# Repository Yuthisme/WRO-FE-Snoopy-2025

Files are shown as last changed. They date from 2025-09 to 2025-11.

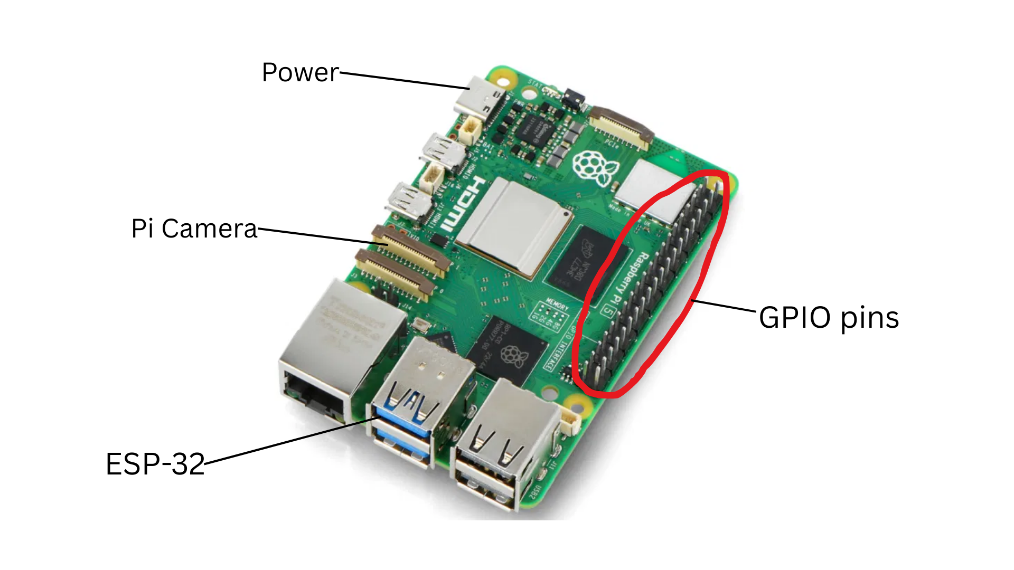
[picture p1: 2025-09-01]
schemes/pi.png

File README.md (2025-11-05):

# <ins> Snoopy: WRO Future Engineer 2025 </ins>
---
## Table of Content
1. [Introduce the team](#1introduce-the-team)
2. [What is WRO?](#2what-is-wro)
   - [Why do we choose Future Engineer](#why-we-chose-future-engineer)
3. [Robot](#3robot)
4. [Video](#4-video)
5. [Hardware](#5-hardware)
   - [Mobility Management](#mobility-management)
     - [3D design](#3d-design)
     - [Motor](#motor)
     - [Differential](#differential)
     - [Steering](#steering)
     - [Chassis](#chassis)
     - [Assembly](#assembly)
   - [Power and Sense management](#power-and-sense-managament)
     - [Component](#component)
     - [Sensor](#sensor)
     - [Power Supply](#power-supply)
     - [Microcontroller](#microcontroller)
     - [Wiring and Scheme](#wiring-and-scheme)
6. [Software](#6software)
   - [ROS2](#ros2)
   - [OpenCV](#open-cv)
   - [Code for components](#code-for-component)
7. [Obtacle Management](#7obstacle-management)
   - [Strategy](#strategy)
     - [Opene Challenge](#open-challenge)
     - [Obstacle Challenge](#obstacle-challenge)
8. [Conclusion](#8-conclusion)
---
# 1.Introduce the team
---
<p>

</p>
<p><ins><i>Snoopy at WRO INTERNATIONAL 2024</i></ins></p>

Snoopy is a team of passionate young engineers. We started back in grade 11(2024), when three high school students and our robotics teacher teamed up after being inspired by our seniors winning the Startup Idea Award at the WRO International Round in Panama. Last year, we joined the World Robotics International Round in Türkiye, where we learned a lot and made plenty of new friends. [Instagram](https://www.instagram.com/snoopy.cambodia?utm_source=ig_web_button_share_sheet&igsh=ZDNlZDc0MzIxNw==)

---
### Snoopy's Team:
<p>
1. Reaksa Chhoeun<br>
<br>
- Team's Advisor<br>
- "Don't give up"<br>
</p>

<p>
2. Seyha Hoy<br>
<br>
- Team's Coach<br>
- "Stay Curious"<br>
</p>

<p>
3. Leangheng Vongchhayyuth<br>
<br>
-Team's Leader<br>
-Team's coder<br>
-16 years old<br>
-<b>School:</b> AUPP High School-Foxcroft Academy<br>
-"God did"<br>
</p>

<p>
4. Bunchhoeun Rattanakboth<br>
<br>
-Team's mechanics<br>
-16 years old<br>
-<b>School:</b> AUPP High School-Foxcroft Academy<br>
-"What Should I say?"<br>
</p>

<p>
5. Sreng Kimroathpiseth<br>
<br>
-Team's wiring<br>
-17 years old<br>
-<b>School:</b> AUPP High School-Foxcroft Academy<br>
-"Bro idk too"<br>
</p>

<br>
<p><ins><i>Team Picture with coach</i></ins></p><br>
<br>
<p><ins><i>Team Picture</i></ins></p><br>
   
---
# 2.What is WRO?
---
WRO (World Robotics Olympiad) is a global robotics competition for young people. It aims to foster creativity, design, and problem-solving skills through challenging and educational robotics activities. WRO involves teams designing and programming robots to complete tasks or solve problems in various categories. [link](https://wro-association.org/)

## Why we chose Future Engineer?

Future Engineer is one of the interesting categories out of all four, because we love to do challenging and complicated things. We chose this category because we all have an interest in cars and want to be involved in that type of engineering, which is our goal to become engineers in the future.

---
# 3.Robot
---

<br>
<p><i>Front</i></p><br>
<br>
<p><i>Back</i></p><br>
<br>
<p><i>Right</i></p><br>
<br>
<p><i>Left</i></p><br>
<br>
<p><i>Top</i></p><br>
<br>
<p><i>Bottom</i></p><br>

---
# 4. Video
---
- [Youtube](https://youtube.com/@snoopywrocambodia?si=DruGofx_E3J2LwbV)
  - [Open Challenge](https://youtu.be/84BnV2V4fig?si=563qHp9vC6NSgZDj)
  - Obstacle Challenge

---
# 5. Hardware
---
Our robot is built to meet all the game’s requirements. It runs on two motors: one for steering and one for driving. For sensors, we use LiDAR to detect walls, a camera to recognize traffic light colors in the obstacle challenge, and an IMU to track the car’s position.

## Mobility management
### 3D design
   <P>Some parts of our robot were 3D design on our own, and some parts we found online and modified them.</P><br>

| Owned 3D design | Online 3D design  |
|--- |--- |
| [Robot's Layer](https://github.com/Yuthisme/WRO-FE-Snoopy-2025/blob/main/models/the%20robot.f3z)| [Differential Grear](https://github.com/Yuthisme/WRO-FE-Snoopy-2025/blob/main/models/differenetial%20gear.f3d)|
| [Camera mount](https://github.com/Yuthisme/WRO-FE-Snoopy-2025/blob/main/models/cam%20mount.f3d)| [Differential Case](https://github.com/Yuthisme/WRO-FE-Snoopy-2025/blob/main/models/differential%20case.f3d) |
| [Battery Checker Holder](https://github.com/Yuthisme/WRO-FE-Snoopy-2025/blob/main/models/bat%20checker%20v5.f3d)| |
| [Battery Holder](https://github.com/Yuthisme/WRO-FE-Snoopy-2025/blob/main/models/battery%20holder_.f3d)| |
|[Right rear wheel holder](https://github.com/Yuthisme/WRO-FE-Snoopy-2025/blob/main/models/right%20rear%20wheel%20holder.f3d)| |

#### Robot's Layer
<br>
The robot’s chassis is built in three layers: bottom, middle, and top.<br>
  - <b> Chassis: </b> This layer houses the motors with encoders, the steering servo, and the differential. A cutout at the rear of the chassis accommodates the differential, ensuring smooth operation. At the front, the servo and servo rod control the steering of the front wheels.
  - <b> Middle Layer: </b> This layer supports most of the sensors and electronic components, including the camera, LiDAR, motor driver, camera mount, ESP32, battery, and battery checker.
  - <b> Top Layer: </b> The top layer is reserved for the main computing and power components, such as the Raspberry Pi 5, our custom-designed PCB, and the buck converter.

#### Camera Mount:
  <br>
 The camera mount is positioned high to allow the camera to easily detect traffic lights during the obstacle challenge. Its base is precisely aligned with the LiDAR mounting screw holes, as the LiDAR is mounted directly beneath the camera. 
 
#### Battery Checker Holder:
bat checker<br>
This holder is designed to securely house the battery checker at the back of the robot. The holder’s hole is 10 mm larger than the battery checker to ensure a snug fit.

#### Battery Holder
bat holder<br>
The battery holder is designed to secure the battery in place. Similarly, its hole is 10 mm larger than the battery to prevent it from falling out while the robot is in motion.

#### Right Rear Wheel Holder
<br>
This component stabilizes the drive shaft extending from the differential to the right rear wheel.

#### Differential Gear
  <br>
   We sourced the design from GrabCAD and modified the central hole of the gear to fit the motor shaft precisely.[link](https://grabcad.com/library/lego-technic-gears-1)
   
#### Differential Case
  <br>

  We adapted the design from [Team StormsNGR](https://github.com/MoCsabi/WRO2024-FE-StormsNGR/blob/main/models/Differential%20Gear%20House.stl), modifying certain parts to accommodate a different motor and to provide a secure mount for the motor.

### Motor
<br>
We selected the JGB37-520B DC motor with encoder to track the distance traveled by the robot. This allows us to determine the motor’s speed, control when the robot needs to turn, and monitor wheel rotations. As a result, the robot can stop precisely at its starting point and execute accurate left and right turns.

### Differential
<br>

The robot uses a LEGO differential, which allows the left and right wheels to rotate at different speeds when turning, enabling smooth cornering. We also chose this differential because it easily connects to the LEGO wheels used on the robot, simplifying assembly and ensuring reliable performance.

### Steering
Front Wheel<br>
The robot uses a servo motor and a servo rod for steering. The servo is controlled to rotate at specific angles using a PID controller. The servo rod is attached to an arm connected to the servo shaft, which pushes or pulls the linkage as the servo rotates, causing the wheels to pivot in the desired direction.

### Chassis
<br>

- <b>Front section</b>: Designed to allow smoother turning and wheel rotation without interference from other parts of the robot. This section also accommodates the servo motor.
- <b>Middle section</b>: Serves as the mounting area for the motor. The motor driver and LiDAR are mounted upside down on the second layer of the car, connected above this section.
- <b>Rear section</b>: Houses the differential and rear wheels, with a cutout that allows the differential to rotate freely. This section also connects the rear wheels to the differential.

### Assembly
#### Design and Planning
<b>Step 1:</b>  We searched up some designs of the chassis online or took a look at last season's teams for inspiration.<br>
<b>Step 2:</b> We discuss and finalize the design <br>
<b>Step 3:<b> We start to design the chassis, the 1st and 2nd layer,  then the other components mount of the robot.<br>
<b>Step 4:</b> We decide what material to use for the chassis, the robot’s layer, and the components mount.<br>

#### Fabrication
- For the Chassis, we chose aluminum since it’s light and strong.
- For the robot’s layer, we use acrylic; it’s light, strong, and easy to laser cut.
- For the other component’s mount, we 3D printed it.

#### Assembly

Step 1: Cut out the car chassis using Aluminum<br>
Step 2: 3D print the Camera Mount, Differential Case, Battery  Holder, Battery Checker Holder, Right Rear Wheel Holder and the Differential Gear.<br>
Step 3: Cut the Middle layers and the Top layers with Acrylic.<br>
Step 4: Installation of the Chassis<br>

<br>

1. Connect the servo’s mount, then connect it to the Servo
2. Connect the Servo arm to the servo 
3. Connect the servo rod with the servo arm
4. Connect the steering with the wheel
5. Install the differential, the wheel, and the motor

Step 5: Installation of the middle layer<br>



1. Connect the camera mount with the lidar 
2. ESP-32 behind the camera mount
3. The motor driver behind the lidar
4. Install the battery holder
5. Install the battery checker holder

Step 8: Installation of the top layer<br>

<br>

1. The PCB at the front
2. The Raspberry Pi 5 in the middle
3. The buck converter must be at least 50mm longer.

<i>Note: We install the chassis, then continue installing the 2nd and 3rd layer by putting them on top of each other.</i>

## Power and Sense Managament
### Component
At the core of our robot, we have a Raspberry Pi 5 with 8GB of RAM. This Raspberry Pi 5 processes all the data sent to the robot by the other components, such as the lidar, camera, motor, and IMU. Here are the listing and purpose:

<p><b>IMU (Inertial Measurement Unit)</b></p><br>
<p>A device that measures the orientation and acceleration of a moving object. In our self-driving robot, the IMU provides crucial information about the robot's orientation, angular velocity, and linear acceleration. This data is essential for vehicle state estimation, sensor fusion, and control systems.</p><br>

<p><b> LiDAR (Light Detection and Ranging)</b></p><br>
<p>It emits laser beams to measure distances to objects in its surroundings. It provides a 3D point cloud representation of the environment, enabling the robot to perceive obstacles, terrain, and other relevant features. Key applications of LiDAR in your self-driving robot include obstacle detection and avoidance, mapping and localization, and terrain analysis.</p><br>

<p><b> Raspberry Pi 5 16GB RAM</b></p><br>
<p>The Raspberry Pi 5 serves as the brain of our self-driving robot. It processes sensor data, executes control algorithms, and communicates with other components. Key functionalities of the Raspberry Pi 5 in your robot include sensor data processing, algorithm execution, communication, and machine learning.</p><br>

<p><b> Motor Driver</b></p><br>
<p>A motor driver is an electronic circuit that controls the speed and direction of electric motors. It acts as an interface between the Raspberry Pi 5 and the motors, allowing the robot to move forward and backward. Key features of a motor driver include power amplification, direction control, and speed control.</p><br>

<p><b>Motor</b></p><br>
<p>Motors are the actuators that convert electrical energy into mechanical energy, enabling the robot to move. In our self-driving robot, motors are typically used to drive the wheels. Key characteristics of motors for self-driving robots include torque, speed, and efficiency.</p><br>

<p><b> Servo Motor </b></p><br>
<p>A servo motor is a rotary actuator with a built-in position sensor. It allows precise control of the angle of rotation, making it ideal for steering mechanisms in self-driving robots. Key features of a servo motor include precision and holding torque.</p><br>

<p><b>Raspberry Pi Camera Module 3</b></p>
<p>The Raspberry Pi Camera Module 3 is a 12MP Sony IMX708 autofocus camera; stills up to 4608×2592, video up to 1080p60, with HDR and improved low-light; CSI ribbon connection; works with Picamera2/OpenCV.</p><br>
 
<p><b>ESP32</b></p><br>
<p>The ESP32 is a powerful microcontroller with built-in Wi-Fi and Bluetooth. It has many pins for sensors and devices, making it popular for IoT, robotics, and smart gadgets. It’s low-cost, fast, and easy to program with Arduino or MicroPython. We use this to receive data from the Lidar and send the data to the Raspberry Pi</p><br>

<p><b>RGB</b></p><br>
<p>RGB stands for Red, Green, and Blue, the three primary colors of light. By mixing these colors in different intensities, almost any other color can be created. We use this to tell the status of the robots.</p>

### Sensor
Our robots use multiple sensors for different purposes, like the Lidar we use to detect the wall since it uses lasers to measure the distance between the wall and the robot, so it’ll make it easy to identify how far or how close the robot is when we test the robots in both open and obstacle challenges. The other sensor that we use is the Camera, which we use to detect the color of the traffic light during the obstacle challenge, so it can send a signal to the robot that either turn left or right. We also use IMU to track the position of the robot, we use it to count how many laps the robot has traveled, and to make the robot move in a fixed position.

### Power Supply
We chose an 11.1V LiPo battery since it can provide us with enough power to run all of our components, such as the Raspberry Pi, servo, motor, and sensors. Since the servo, IMU, and motor encoder have a maximum voltage of 5V, we use a buck converter to step down the 11.1V from the battery to 5V, which is then supplied to the components that require only 5V. Additionally, we use a boost converter to step up the 11.1V to 12V to power the motor.

### Microcontroller
The robot Raspberry Pi serves as the main controller, managing all operations. We selected the Raspberry Pi for its processing speed, ease of integration with other components, and the ability to upload or modify code via SSH, eliminating the need to connect a USB cable like with Arduino or ESP32.

### Wiring and Scheme
<p>For wiring, we chose to design our own PCB board that has all the pins that indicate each GPIO pin of the Raspberry Pi 5 and a JST pin for power supply, RGB, Motor encoder, Motor Driver, Motor, IMU, and push button. The screw terminal connectors for the power supply.</p><br>
pi<br>
<br>
<br>
<p>This schematic illustrates a robot control system designed around a Raspberry Pi 5, featuring an IMU for orientation, encoders for wheel feedback, DC motors for driving, and a servo for steering or actuation.</p>

---
# 6.Software
---
	
 We decided to use ROS2 as the main framework for our robots, while OpenCV for the camera. ROS2 provides the communication framework that connects different parts of the system, while OpenCV enables the car to process camera images and recognize objects. Together with sensors like LiDAR and cameras, they allow the robot to detect obstacles, identify lanes, and make driving decisions. For the full software documentation including solutions and how we approach problem please go to [CODE DOCUMENTATION](src/README.md).

## ROS2

<br>

ROS2, the Robot Operating System 2, acts as the central nervous system of the self-driving car. It provides a flexible framework for organizing and coordinating various software components, including nodes, topics, and services. Nodes perform specific tasks, such as sensor data processing, control algorithms, or communication with other nodes. Topics are channels for publishing and subscribing to messages, enabling data exchange between nodes. Services provide a request-response mechanism for nodes to interact and request services from each other.

## Open CV

OpenCV, the Open Source Computer Vision Library, empowers the car to "see" the world around it. It enables a wide range of computer vision techniques, including image processing, feature detection, object detection and tracking, and optical flow.

To integrate these components, a ROS2-based system is meticulously crafted. LiDAR data is captured and processed to generate a point cloud representation of the environment, while camera images are captured and pre-processed using OpenCV to enhance clarity and contrast. LiDAR-based perception uses point cloud data to detect obstacles and create a 3D map of the surroundings, while camera-based perception employs OpenCV to identify lanes, traffic signs, and other relevant visual cues.

## Code for Component
- [IMU](src/bno055_imu)
- [Messages](src/fe_interfaces)
- [Hole Checker](src/find_hole)
- [Lidar Package for ROS2](src/ldlidar_stl_ros2)
- [Lidar Codes](src/lidar_ros2)
- [Motor Control](src/motor_control)
- [Robot automation](src/my_robot)
- [Object Detection](src/object_detection)
---
# 7.Obstacle Management

There are two challenges: the Open Challenge and the Obstacle Challenge. The open challenge requires the robot to drive three full laps around the game field and stop at its starting point. While the Obstacle challenge requires the robot to drive 3 full laps too but there are traffic lights and a parking lot. GREEN = right, RED = left. [Officials Game Rule](https://wro-association.org/wp-content/uploads/WRO-2025-Future-Engineers-Self-Driving-Cars-General-Rules.pdf)

## Strategy 
### Open Challenge
<br>
Our robot begins its run when the push button is pressed, activating its wall-tracking system. Using LiDAR and IMU data, the robot simultaneously monitors both the left and right walls to stay centered. When the left or right wall shows a gap (detected as a hole), the robot recognizes it as a turn. It then follows the wall, making a precise 90° turn, which is counted as one completed turn. If no hole is detected, the robot continues moving forward while keeping track of both walls. The ESP32 ensures fast and reliable data transfer from the LiDAR to the Raspberry Pi 5, which fuses data from the IMU and Pi Camera Module v2 for orientation, stability, and lane recognition. After completing 12 turns, the robot executes a controlled stop. This strategy minimizes wall contact, ensures stable turns, and achieves accurate lap completion.

### Obstacle Challenge
In the Obstacle Challenge, our approach is extended to include traffic sign recognition and parking. The camera identifies red and green pillars, which dictate whether the vehicle should stay on the right or left side of the lane. The LiDAR, with data again transmitted through the ESP32 module, confirms obstacle distances and ensures safe path planning, while the IMU stabilizes navigation during detours. The Raspberry Pi 5 executes a state-machine control system that interprets sign information, chooses the correct lane, and adjusts the steering smoothly to avoid moving signs, since avoiding contact yields higher points. After completing three laps, the camera and LiDAR are used together to detect the magenta parking lot boundaries. The vehicle then executes a precise parallel parking maneuver, carefully controlling the steering servo and motors to ensure it is fully inside the parking space without touching the barriers. The RGB LEDs signal the vehicle’s status throughout (ready, running, or parking), helping the team and judges monitor progress.

---
# 8. Conclusion
Through countless hours of design, coding, testing, and teamwork, Team Snoopy Cambodia has developed a robot that balances innovation with reliability. By combining ROS2, OpenCV, LiDAR, IMU, and a Raspberry Pi 5, we created a self-driving system capable of navigating open tracks, handling obstacles, and performing precise self-parking.<br>
This journey has been more than just building a robot it has been about learning, problem-solving, and pushing our creativity to new levels. Each challenge taught us how to improve our engineering, strengthen our teamwork, and bring our vision closer to reality.<br>
As we move forward to WRO 2025, we are proud of what we’ve achieved and excited to keep innovating, improving, and representing Cambodia on the international stage.

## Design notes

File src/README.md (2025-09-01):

Control software
====

### OPEN CHALLENGE 

For open challenge, our approach to the problems are very simple. This could be changed later if we qualified to international rounds, however for the current national rounds the solutions will be very simple as the inside wall of the gamefield is static. 

Firstly, before the robot needs to do anything it needs to check whether its going clockwise or counter-clockwise. The solution for this problem is to check for the hole before it **reaches** the hole. To do this we had to do some basic trigonometry:

 

We check for holes using a static range in our LiDAR scanner, for example we want to check from 30-60cm in front of us. We would first use the Pythagorean theorem: $a^2 + b^2 = c^2$. We then do this for another hypotenuse as there are 2 range, 30cm and 60cm. Using the two hypotenuse we can find the angle by using: $Tan(θ) = opposite/adjacent$. After finding out this angle we can use it into our code to scan for those specifics angles, and there will be specific ranges we can use to compare to the angle to check whether those laser beams past through our ranges or not. If all of the laser beams divided by 2 passes through our range, then it would be considered a wall. 

Moving on here is a flowchart of how the first part of our open challenge round will be like.

```mermaid
flowchart TD
    A(["Button pressed"]) --> B{"Check Both Side for Hole"}
    B --> C["Hole Left"] & D["No Hole"] & n1["Hole Right"]
    C --> n2["Track Left Wall"]
    D --> n3["Track Both Wall"]
    n1 --> n4["Track Right Wall"]
    
```

After tracking the walls, we move on to our turning segment of the algorithm. Since we have an IMU that we can fully utilize, we use that IMU to check for every turn and record it until it hits 12, then the robot will stop. We have a set of array that stores the angles in radians for all the 4 turns the robot will commit to during the round. It will loop through the array and compare the real IMU data to this array, and will add 1 turn for everytime the IMU matches the array.

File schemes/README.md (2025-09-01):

Electromechanical diagrams
====

This directory gives u all the file for our pcb and the pin

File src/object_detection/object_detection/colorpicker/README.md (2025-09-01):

# OpenCV Shape and Color Detection

This project demonstrates shape and color detection using OpenCV. It includes scripts for detecting shapes and colors in images and video streams.

## Project Structure

```
.
├── colorDetection.py   # Detects green, and red colors in an image
├── hextohsv.py         # Converts hex color codes to HSV 
├── obstacle.jpg        # Sample image for color detection
└── README.md
```

## Requirements

- Python 3.x
- OpenCV
- NumPy

You can install the required packages using pip:

```sh
pip3 install opencv-python numpy
```

## Color picker
[Color picker](https://imagecolorpicker.com/)

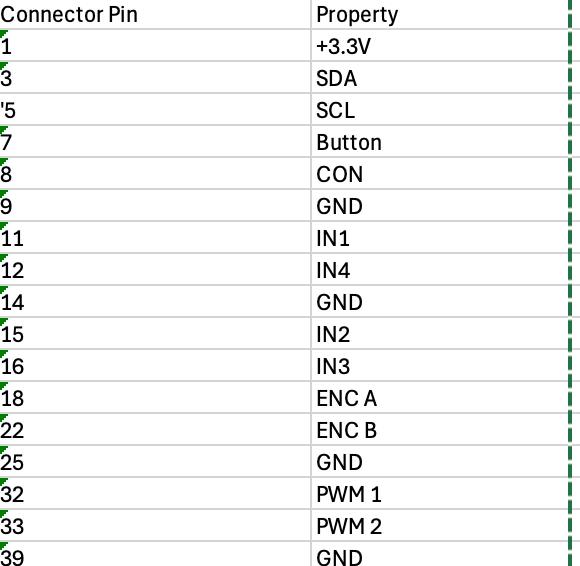
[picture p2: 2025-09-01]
schemes/pins.jpg

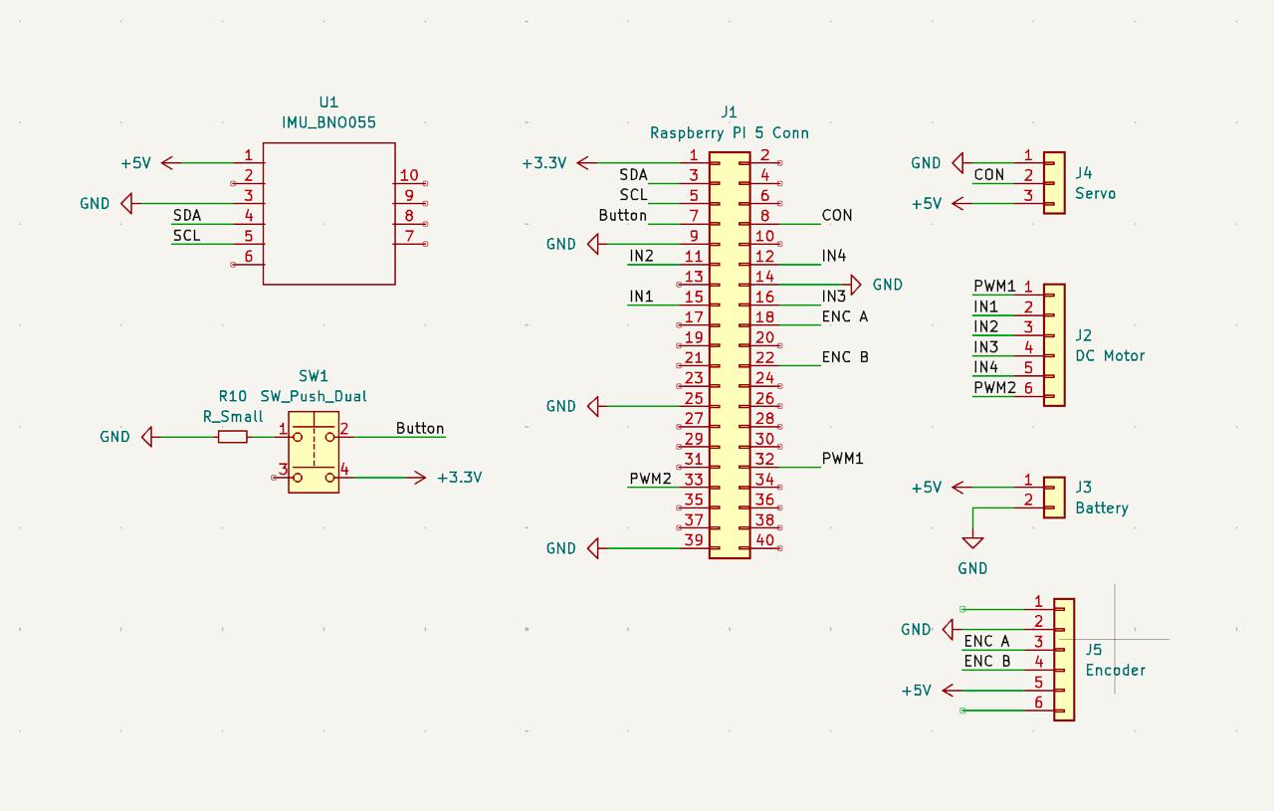
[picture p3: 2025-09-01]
schemes/connections.jpg

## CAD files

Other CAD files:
models/1st layer front.f3d
models/1st layer rear.f3d
models/2nd layer_.f3d
models/bat checker v5.f3d
models/battery holder_.f3d
models/cam mount.f3d
models/car_chassis.f3d
models/differenetial gear.f3d
models/differential case.f3d
models/right rear wheel holder.f3d

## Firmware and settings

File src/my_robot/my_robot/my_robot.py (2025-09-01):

import rclpy
import math
import numpy as np
import time
from gpiozero import Button

from rclpy.node import Node
from std_msgs.msg import String
from gpiozero import Button  # Import Button from gpiozero
from fe_interfaces.msg import Angle, MotorControl, Holes
from my_robot.PID import PID
from sensor_msgs.msg import Imu
from geometry_msgs.msg import Quaternion, Point


class ExampleNode(Node):
    def __init__(self):
        super().__init__('example_node')
        self.publisher_button = self.create_publisher(String, 'button', 10)
        self.angle_subscriber = self.create_subscription(Angle, 'angles', self.angle_callback, 10)
        self.publisher_ = self.create_publisher(MotorControl, 'motor_control', 10)
        self.imu_subscriber = self.create_subscription(Imu, 'imu/data', self.imu_callback, 10)
        self.object_subscriber = self.create_subscription(Point, '/object_detection', self.object_callback, 10)
        self.holes_sub = self.create_subscription(Holes, "hole", self.hole_callback, 10)


        # self.timer = self.create_timer(1.0, self.publish_message)

        # Set up GPIO pin 4 as an input button
        self.button = Button(4)
        
        self.start = False
        self.turn = False
        self.initial = True
        self.turn_counter = 0
        self.hole = Holes()

        # Add a listener to the button press
        
        self.get_logger().info("Listening for button presses on GPIO pin 13.")
        # self.button.when_pressed = self.on_button_press()
        
        # mode for open or obstacle challenge
        self.mode = True

        self.target_heading_rev = np.array([math.pi/2, math.pi, (3*math.pi)/2, (2*math.pi)])
        self.target_heading = np.array([(3*math.pi)/2, math.pi, math.pi/2, 0.0])

        self.prev_angle = 0.0
        self.current_angle = 0.0

        self.move_pid = PID(0, 11,0.1)
        self.move_object_pid = PID(0, 0.02,0.02)
        self.turnOutput = PID(0, 2, 0, 0.08)
        self.turn_pid = PID(0, 10,0.01)

        self.imu = Imu()
        self.angle = Angle()
        self.corrected_yaw = 0.0

        self.turnSettled = self.turnOutput.is_settled()

        self.is_turning = False  # Track if the robot is currently turning
        self.turn_target_yaw = 0.0  # Store target yaw for the turn
        self.turning = 0


        # for obstacle_challenge
        self.object = Point()

    def hole_callback(self, msg):
        self.hole = msg

    def object_callback(self, msg):
        self.object = msg

    def imu_callback(self, msg: Imu):

        """1. get the IMU roll angle.
        2. get the traget angle from the taget heading arrays(clockwise or counter_clockwise)
        3. check if the robot reaches the target heading 
        """
        self.corrected_yaw = msg.orientation.x
        # Normalize corrected yaw to be within [-2PI, 2PI]
        # if self.imu.orientation.x > math.pi:
        #     self.corrected_yaw -= 2 * math.pi
        # elif self.imu.orientation.x < -math.pi:
        #     self.corrected_yaw += 2 * math.pi

        
        self.prev_angle_angle = self.corrected_yaw
        

    def normalize_yaw(self, yaw):
        # Normalize yaw to be within -pi to pi
        while yaw > math.pi:
            yaw -= 2 * math.pi
        while yaw < -math.pi:
            yaw += 2 * math.pi
        return yaw
        

    def angle_callback(self, msg: Angle):
        """
        1. the autonomous code: mode true -> open challeng; mode -> false -> obstacle
        2. starts when the button is pressed
        """
        # self.get_logger().info(f"button: {self.button.when_released}")
        self.button.when_released = self.on_button_press
        if self.start:
            self.angle = msg
            turnOutput_PID = self.turnOutput.calculate_pid_output((math.pi/2) - (self.corrected_yaw))

            if self.mode:

                if self.turn_counter == 12:
                    self.stop()
                    self.get_logger().info(f"Turning completed")
                else:
                    if msg.angles[3] > 0.01 and self.is_turning == False:
                        self.get_logger().info(f"Turn: {self.turn}")
                        # self.get_logger().info(f"Moving forward{msg.angles[3]}")
                        self.move_forward(msg)
                    
                        if self.hole.rotation != 0:
                            if self.hole.rotation == 1: #Counter Clockwise
                                self.turn = False
                            else: #Clockwise
                                self.turn = True

                        self.get_logger().info(f"Turn: {self.turn}")
                        
            else:
                self.get_logger().info(f"Obstacle challenge")
                self.avoid_object(msg)

    def avoid_object(self, msg_angle: Angle):
        """
        1. if obstacle run the code
        2. if the object is furthur than 0.006 place the object red: on the right of the frame; green: on the left of the frame
        3. 1 = red, 0 = green, -1 = no objects
        4. if there is no object and teh disatance is less than 0.006 move to the center of the game field
        """
        msg = MotorControl()
        msg.forward = True
        msg.speed = 0.28
        # msg.speed = 0.3
        # msg.speed = 0.28
        msg.angle = 20.0
        msg.stop = False

        if self.mode:
            error = msg_angle.angles[2] - msg_angle.angles[0]
            pid_output = self.move_pid.calculate_pid_output(error)
            angle = self.clamp(12.0 - pid_output, 3.0, 20.0)
            msg.angle = angle
        else:
            if self.object.y > 0.006:
                if self.object.x == 1.0:
                    error = self.object.z + 300.0
                elif self.object.x == 0.0:
                    error = self.object.z - 300.0
                self.get_logger().info(f"Error: {self.object.z}")
                pid_output = self.move_object_pid.calculate_pid_output(error)
                self.get_logger().info(f"PID: {pid_output}")
                angle = self.clamp(12.0 + pid_output, 0.0, 20.0)
                msg.angle = angle
            elif self.object.x == -1.0:
                error = msg_angle.angles[2] - msg_angle.angles[0]
                pid_output = self.move_pid.calculate_pid_output(error)
                angle = self.clamp(12.0 - pid_output, 0.0, 20.0)
                msg.angle = angle
        # self.get_logger().info(f"Forward: {self.turn_counter}")
        # self.get_logger().info(f"Angle: {msg.angle}")
        # self.get_logger().info(f"PID: {pid_output}")
        self.publisher_.publish(msg)
        # self.get_logger().info(f"Moving forward")


    
    def move_forward(self, msg_angle: Angle):
        
        """
        1. find the difference between the left and right lidar
        2. take the error and input into PI
        3. center the robot
        """
        msg = MotorControl()
        msg.forward = True
        msg.speed = 1.0
        # msg.speed = 0.3
        # msg.speed = 0.28
        msg.angle = 22.0
        self.is_turning == False
        msg.stop = False

        if self.mode == True:
            self.get_logger().info(f"Turn: {self.turn}")
            
            if self.turn: #Counter Clockwise
                error = self.target_heading[self.turn_counter%4] - self.corrected_yaw
                self.turn_target_yaw = self.target_heading[self.turn_counter%4]
                # error = math.pi/2 - (self.corrected_yaw - self.prev_angle)
            else: #clockwise
                error = self.target_heading_rev[self.turn_counter%4] - self.corrected_yaw
                self.turn_target_yaw = self.target_heading_rev[self.turn_counter%4]

            # self.get_logger().info(f"Turn: {self.turn}")
            # self.get_logger().info(f"target: {self.target_heading}")
            # self.get_logger().info(f"yaw: {self.corrected_yaw}")
            # self.get_logger().info(f"Error Turning: {abs(error)}")
            # self.get_logger().info(f"Counter: {self.turn_counter}")
        
            #check if the robot reaches the traget heading
            if abs(error) < 0.1:  # Threshold for completing the turn
                self.turn_counter += 1
                self.is_turning = False  # End turning state
                self.get_logger().info("Turn completed. Moving forward.")

        if self.hole.rotation == 2:
            error = msg_angle.angles[2] - 0.50 #track the RIGHT wall
            self.get_logger().info(f"tracking RIGHT {msg_angle.angles[2]}")
            # self.turning = self.target_heading_rev[self.turn_counter%4] - self.corrected_yaw
            
        elif self.hole.rotation == 1:
            error = 0.50 - msg_angle.angles[0]  #track the LEFT wall
            self.get_logger().info(f"tracking LEFT {msg_angle.angles[0]}")
            
            # self.turning = self.target_heading[self.turn_counter%4] - self.corrected_yaw
        else:
            error = msg_angle.angles[2] - msg_angle.angles[0] #track both side because no hole known yet.
            self.get_logger().info(f"tracking BOTH")

        # if abs(self.turning) < 0.05:
        #     self.turn_counter += 1

        pid_output = self.move_pid.calculate_pid_output(error)
        angle = self.clamp(20 + pid_output, 10.0, 27.0)
        msg.angle = angle
        self.get_logger().info(f"Forward: {self.turn_counter}")
        self.get_logger().info(f"ERROR: {error}")
        self.get_logger().info(f"Angle: {msg.angle}")
        # self.get_logger().info(f"PID: {pid_output}")
        self.publisher_.publish(msg)
        # self.get_logger().info(f"Moving forward")
    
    def start_turn(self):
        """
        1. start the turning the state
        2. true: right; false: left
        """
        self.get_logger().info(f"Turning in progress")
        # Set target yaw for a 90-degree turn, adjusting based on current yaw
        if self.turn:
            self.turn_target_yaw = ((math.pi*3)/2)
        else:
            self.turn_target_yaw = (math.pi/2)
        # self.turn_target_yaw = self.normalize_yaw(self.turn_target_yaw)
        
        # Enter turning state
        self.is_turning = True
        self.get_logger().info(f"Turn: {self.turn}")
        if self.turn:
            self.get_logger().info("Turning right")
            self.turn_right()
        else:
            self.get_logger().info("Turning left")
            self.turn_left()

    def turn_left(self):
        msg = MotorControl()
        msg.forward = True
        msg.speed = 0.0
        msg.stop = False
        # msg.angle = 20.0
        self.is_turning == True
        self.publisher_.publish(msg)
        turnOutput_PID = self.turnOutput.calculate_pid_output(self.corrected_yaw - self.target_heading_rev[self.turn_counter%4])
        error = (-1 * self.target_heading_rev[self.turn_counter%4]) + self.corrected_yaw
        pid_output = self.turn_pid.calculate_pid_output(error)
        self.get_logger().info(f"PID Turn: {pid_output}")
        angle = self.clamp(5 + pid_output, 3.0, 12.0)
        self.get_logger().info(f"Angle: {angle}")
        msg.angle = angle
        self.publisher_.publish(msg)
    
    def turn_right(self):
        msg = MotorControl()
        msg.forward = True
        msg.speed = 0.0
        msg.stop = False
        msg.angle = 20.0
        self.publisher_.publish(msg)
        turnOutput_PID = self.turnOutput.calculate_pid_output(self.target_heading[self.turn_counter%4] - (self.corrected_yaw))
        error = self.target_heading[self.turn_counter%4] - self.corrected_yaw
        pid_output = self.turn_pid.calculate_pid_output(error)
        angle = self.clamp(20.0 + pid_output, 0.0, 24.0)
        msg.angle = angle
        self.publisher_.publish(msg)
        

    def stop(self):
        msg = MotorControl()
        msg.stop = True
        msg.forward = False
        self.publisher_.publish(msg)
        self.get_logger().info(f"Stopping")

    def clamp(self,input_value, min_value, max_value):
        if input_value > max_value:
            return max_value
        if input_value < min_value:
            return min_value
        return input_value

    def publish_message(self):
        msg = String()
        msg.data = 'Button not pressed'
        self.publisher_button.publish(msg)
        # self.get_logger().info(f'Published: {msg.data}')

    def on_button_press(self):
        msg = String()
        msg.data = 'Button pressed!'
        self.start = True
        self.publisher_button.publish(msg)
        self.get_logger().info(f'Published: {msg.data}')

def main(args=None):
    rclpy.init(args=args)
    node = ExampleNode()
    rclpy.spin(node)
    node.destroy_node()
    rclpy.shutdown()

if __name__ == '__main__':
    main()

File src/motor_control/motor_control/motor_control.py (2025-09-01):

import rclpy
from rclpy.node import Node
from gpiozero import OutputDevice, PWMOutputDevice, AngularServo
from fe_interfaces.msg import MotorControl # Replace with your actual package name

class Motor:
    def __init__(self):
        # Initialize the motor control pins and PWM for speed control
        self.IN1 = OutputDevice(22)
        self.IN2 = OutputDevice(17)
        self.IN3 = OutputDevice(23)
        self.IN4 = OutputDevice(18)
        self.pwm1 = PWMOutputDevice(12)
        self.pwm2 = PWMOutputDevice(13)
        self.servo = AngularServo(14, min_angle=0, max_angle=37, min_pulse_width=0.5/1000, max_pulse_width=2.5/1000, initial_angle=None)

        # self.button = gpiozero.Button(27)


  
    def forward(self, speed):
        # Set the motor speed for forward direction
        self.pwm1.value = speed
        self.pwm2.value = speed
        self.IN1.value = False
        self.IN2.value = True
        self.IN3.value = True
        self.IN4.value = False

    def reverse(self, speed):
        # Set the motor speed for reverse direction
        self.pwm1.value = speed
        self.pwm2.value = speed
        self.IN1.value = True
        self.IN2.value = False
        self.IN3.value = False
        self.IN4.value = True

    def stop(self):
        # Stop the motor by setting PWM to zero
        self.pwm1.value = 0
        self.pwm2.value = 0
        # self.cleanup()

    def cleanup(self):
        # Cleanup all GPIO resources
        self.IN1.close()
        self.IN2.close()
        self.IN3.close()
        self.IN4.close()
        self.pwm1.close()
        self.pwm2.close()

    # def cleanup(self):
    #     # Cleanup all GPIO resources
    #     self.IN1.
    #     self.IN2.open()
    #     self.IN3.open()
    #     self.IN4.open()
    #     self.pwm1.open()
    #     self.pwm2.open()
    

class MotorControlNode(Node):
    def __init__(self):
        super().__init__('motor_control_node')
        self.motor = Motor()
        
        # Subscribe to the MotorControl message
        self.subscription = self.create_subscription(
            MotorControl,  # Message type
            'motor_control',  # Topic name
            self.motor_control_callback,  # Callback function
            10  # Queue size
        )
        self.get_logger().info("Motor control node started and subscribed to 'motor_control' topic")

    def motor_control_callback(self, msg: MotorControl):
        # Control the motor based on the received message
        if msg.stop:
            self.get_logger().info("Stopping the motor")
            self.motor.stop()
            self.motor.servo.angle = msg.angle
            self.get_logger().info(f"angle: {msg.angle}")
        elif msg.forward:
            self.get_logger().info(f"Moving forward with speed: {msg.speed}")
            self.motor.forward(msg.speed)
            self.motor.servo.angle = msg.angle
        elif msg.reverse:
            self.get_logger().info(f"Reversing with speed: {msg.speed}")
            self.motor.reverse(msg.speed)
            self.motor.servo.angle = msg.angle

    def destroy_node(self):
        # Ensure the motor is stopped when shutting down
        self.motor.cleanup()
        super().destroy_node()

def main(args=None):
    rclpy.init(args=args)
    motor_control_node = MotorControlNode()

    try:
        rclpy.spin(motor_control_node)
    except KeyboardInterrupt:
        pass
    finally:
        motor_control_node.destroy_node()
        rclpy.shutdown()

if __name__ == '__main__':
    main()

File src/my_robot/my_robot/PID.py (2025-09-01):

class PID:
    def __init__(self, error, kp, ki, settle_error=3, settle_time=0):
        self.error = error
        self.kp = kp
        self.ki = ki
        self.settle_error = settle_error
        self.settle_time = settle_time
        self.time_spent_settled = 0
        self.time_spent_running = 0
        self.settled = False

    def calculate_pid_output(self, error):
        kd = 0.0
        integral = 0.00
        previous_error = 0.0
        proportional = self.kp * error
        integral += self.ki * error
        derivative = kd * (error - previous_error)
        previous_error = error

        if abs(error) < self.settle_error:
            #print(f"fabs(error): {abs(error)}")
            # self.time_spent_settled += 10  # Assuming 10 is the time increment, e.g., milliseconds
            self.settled = True
        else:
            # self.time_spent_settled = 0
            self.settled = False

        return proportional + integral + derivative

    def is_settled(self):
        #print(f"time_spent_settled: {self.time_spent_settled}")
        
        # if self.time_spent_settled > self.settle_time:
        #     return True
        return self.settled
    
